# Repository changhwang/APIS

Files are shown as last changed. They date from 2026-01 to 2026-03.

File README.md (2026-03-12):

# APIS: Automated Polarization Imaging System

APIS (Latin for 'bee') is a control system for an automated 2-axis polarization imaging setup using Arduino, Python (PyQt6), and XIMEA cameras.

---

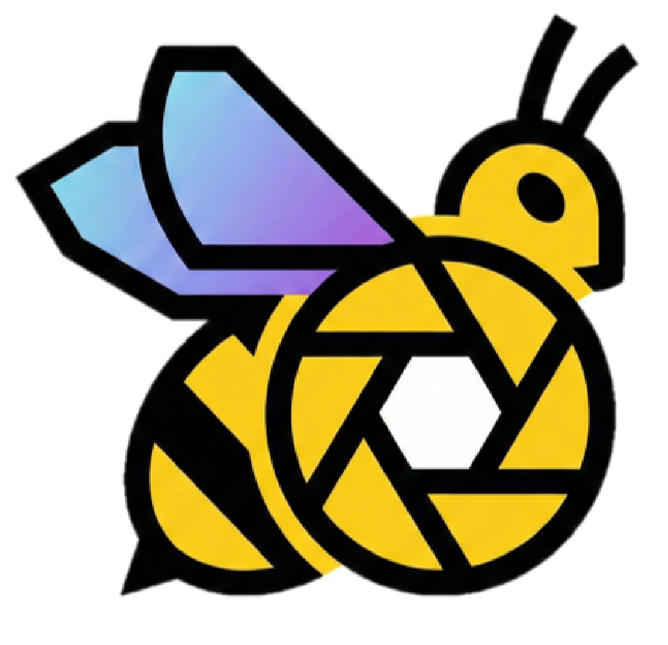
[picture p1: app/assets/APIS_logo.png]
APIS logo


---

## 0. Quick Start
1) Install XIMEA drivers + xiAPI, and flash Arduino firmware
2) Build the hardware by following `docs/hardware_assembly_guide.md` and `docs/implementation_guide.md`
3) Review the calibration notes in `docs/implementation_guide.md`
4) Run `python app/main.py`
5) Connect Camera, Connect Controller, press RESET/ARM, then START SEQUENCE

---

## 1. What You Get

- GUI application (live view, manual motor control, and sequence automation)
- Safety logic (LATCHED/ARMED, ESTOP, RESET)
- Live RGB preview + RGB snapshot capture
- RAW16 sequence capture + CSV/JSON metadata logging
- RAW16 to RGB8 preview conversion tool
- Hardware check tool for quick diagnostics

---

## 2. Requirements

### Hardware
- Hardware assembly guide: `docs/hardware_assembly_guide.md`
  - Follow this guide for the printed parts, stage stack-up, bearings, and gear assembly.
- Hardware implementation guide: `docs/implementation_guide.md`
  - Follow this guide for the physical build, wiring, calibration, and verification steps.
- Controller: Arduino Uno (used in our lab setup; other compatible Arduino boards may also work)
- Polarizer motor (Axis 1): SG90 servo @ Pin 10
- Sample motor (Axis 2): HS-318 servo @ Pin 11
- Camera: XIMEA USB 3.0/3.1 camera
- Polarizer film: Edmund Optics `50 mm Dia. Linear Polarizing Film (XP42-18)`, PN `29490`
- Analyzer polarizer: mount a second linear polarizer in front of the camera lens for cross-polarization imaging
- Backlight: MORITEX MEBL-CW7050 with MLEK-A080W2LR (used in our lab setup)
  - Other backlight models can be used.
  - Mechanical/optical design should be adapted to the selected backlight specifications.
- Bearing balls: McMaster-Carr `9292K74`, hard wear-resistant 52100 alloy steel balls, `5.5 mm` diameter
- Fasteners: M3 screws for printed-part assembly and support-layer fastening
- Threaded inserts: Female-thread brass knurled threaded insert embedment nuts (heat-set inserts)
  - Inserts are embedded into the printed parts with a soldering iron before final mechanical assembly.
- External power adapter: UNIFIVE UN318-1215, 12V 1.5A
- Servo power regulator: LM2596/LM2596S DC-DC buck converter module
  - Example: JTAREA LM2596 adjustable module (4.0-40V to 1.25-37V, 2A, LED voltmeter)
  - Role in this implementation: `VIN/GND` from Arduino feeds the regulator input, and the regulator output powers the HS-318 servo.
- Printed STL parts:
  - `parts/support_1stfloor.stl`
  - `parts/support_2ndfloor.stl`
  - `parts/support_3rdfloor.stl`
  - `parts/support_4thfloor.stl`
  - `parts/polarizer_stage_gear.stl`
  - `parts/film_stage_gear.stl`
  - `parts/servo_gear.stl`
- Power wiring used in this implementation
  - `UNIFIVE UN318-1215 12V 1.5A` powers the Arduino.
  - `Arduino VIN/GND` is connected to the regulator `VIN/GND`.
  - `Arduino 5V/GND` powers the SG90 servo.
  - `Regulator VOUT/GND` powers the HS-318 servo.
  - Arduino and both servos share ground.
- Calibration
  - Both polarizer and sample stages use an image-derived calibration ratio in Python.
  - Current stage calibration is based on `data/calibrationsample/normal`.
  - Current calibrated stage-to-servo ratio is `1.059` for both axes.
  - With the current `0-180` servo command range, the calibrated software max angle is `169 deg` per stage.
  - Re-run calibration after reprinting parts, changing gear fit, or remounting servos.
  - For the cross-polarized crystallinity imaging workflow targeted by this build, the required operating states fall within a limited angular working envelope, so a compact servo-driven transmission was appropriate for the current system.
  - If a future version needs reliable motion well beyond this working envelope, upgrade the mechanical drive by changing the transmission ratio or moving to a stepper-based axis.

### Software
- Python 3.9+
- Arduino IDE (for flashing firmware)
- XIMEA Windows Software Package (drivers + xiAPI)

---

## 3. Installation (Development)

### 3.1 Create venv and install deps
```bash
python -m venv venv
venv\Scripts\activate
pip install -r requirements.txt
```

### 3.2 XIMEA Python API (xiAPI)
The XIMEA Python API is not on PyPI. Install the XIMEA Software Package first, then link the API into your venv.

1. Install the XIMEA Software Package (drivers + API)
2. Locate the API folder (default):
   - `C:\XIMEA\API\Python\v3`
3. Copy the `ximea` folder into:
   - `APIS\venv\Lib\site-packages\`

Verification:
```bash
python -c "import ximea; print('Success')"
```

---

## 4. Quick Start

### 4.1 Flash Firmware
Open `firmware/APIS_Firmware/APIS_Firmware.ino` and upload to your Arduino.

### 4.2 Run GUI
```bash
python app/main.py
```

If you are assembling the hardware from scratch, complete the mechanical assembly in `docs/hardware_assembly_guide.md` and the wiring/verification steps in `docs/implementation_guide.md` before running the GUI.

---

## 5. App Usage Guide

### Safety Bar (Top)
- Shows controller/camera state and current angles/exposure/gain
- ESTOP: immediately cuts motor torque (LATCHED)
- RESET / ARM: re-engages motors (ARMED)
- HOME: moves both motors to 0 degrees

### Device Connections
- Select COM port -> Connect Controller
- Connect Camera
- If XIMEA is not available, the app falls back to DummyCamera

### Manual Motor Control (Absolute Movement)
- Set absolute stage angle within the calibrated software range and click Move
- +45 buttons increment by 45 degrees

### Camera Settings
- Set exposure (us) and gain (dB)
- Click Apply Settings
- The live-view exposure default is `18000 us`
- For the current XIMEA acquisition baseline, auto white balance is disabled during capture.
- Camera gamma is fixed to `1.0` for both live view and sequence capture.
- Fixed white balance is currently `R=1.40`, `G=1.00`, `B=1.20` for both Normal and Crosspol acquisition.
- Re-check the fixed WB values if illumination, analyzer/polarizer alignment, or optics are changed.

### Live View and Snapshot
- Live view uses `XI_RGB24`
- Snapshot saves preview RGB TIFF to the selected folder
- Snapshot metadata is logged to `snapshot_log.csv`

### Sequence Control
- Set Save Directory and Sample ID
- Choose modes: Crosspol / Normal
- Set exposures (defaults: Crosspol `50000 us`, Normal `18000 us`)
- Set angles (list or range, within the calibrated software range)
  - List: `90,60,45,30,0`
  - Range: `0:169:15`
- Settling Time: motor settle delay after each move
- Sequence capture uses `XI_RAW16` only
- During sequence capture, live view is paused and restored after completion
- Sequence images are saved as Bayer RAW `uint16 TIFF` without demosaicing or gamma

### Polarizer Angles (Sequence)
- Crosspol: polarizer moves to 90 degrees
- Normal: polarizer moves to 0 degrees

### Image Conversion
- Convert saved RAW16 TIFFs into confirmation-only `RGB8` previews
- Input scope: the selected folder and its immediate child folders
- Output folder: `<selected_folder>_rgb`
- Conversion pipeline: demosaic (`GBRG`) -> fixed white balance -> gamma `1/2.2`
- Original RAW16 files are preserved

---

## 6. Outputs

- Images:
  - `{SaveDir}/{SampleID}/crosspol`
  - `{SaveDir}/{SampleID}/normal`
- Log file:
  - `{SaveDir}/{SampleID}/{SampleID}_log.csv`
- Sequence metadata:
  - `{SaveDir}/{SampleID}/{SampleID}_metadata.json`
- Snapshot log:
  - `{SaveDir}/snapshot_log.csv`
- Optional RGB preview conversion:
  - `{SelectedFolder}_rgb/`
  - Example: `{SaveDir}/{SampleID}_rgb/crosspol/*_rgb.tif`

---

## 7. Safety Logic

- LATCHED: default on boot or ESTOP, motors detached
- ARMED: motors attached, motion enabled
- Commands are rejected in LATCHED state

---

## 8. Verification

- Automated tests: `tests/test_mock_serial.py`
- Manual hardware check: `scripts/check_hardware.py`
- Raw servo endpoint test (within firmware-supported `0-180` servo range): `scripts/test_servo_limits.py`
- Distribution includes `check_hardware` for quick COM port and ESTOP validation

---

## 9. Build and Distribution (Windows)

Recommended flow:
1) PyInstaller onedir build
2) Zip the dist folder for distribution
3) (Later) Inno Setup for installer packaging

### Build prerequisites
- Use a clean build venv with PyQt6 only (do not install PySide6/PyQt5)
- Icon file: `assets/icon.ico` (already provided)

### Build (spec-based)
- Spec files: `build/apis.spec`, `build/check_hardware.spec`
- Build script: `build/build.ps1`

Example:
```powershell
.\build\build.ps1 -Version 0.1.2
```

### Distribution package
The build script produces:
- `dist/APIS/` (GUI app)
- `dist/check_hardware/` (console tool)
- `release/APIS-win64-vX.Y.Z.zip` containing:
  - `APIS/`
  - `check_hardware/`
  - `README.txt`
  - `prereq_checklist.md`

### XIMEA prerequisite
XIMEA drivers/xiAPI must be installed first. The EXE does not bundle the SDK.

---

## 10. Repository Notes

- `data/`, `dist/`, and `release/*.zip` are ignored by git
- `.vscode/` and `build_venv/` are ignored by git

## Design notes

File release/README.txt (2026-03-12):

APIS (Automated Polarization Imaging System)

Package version: v0.1.2

Installation and Run (Windows)
1) Install prerequisites (see prereq_checklist.md)
2) Unzip the distribution package
3) Run APIS\APIS.exe

Recommended first-time checks
- Connect camera and confirm live view
- Connect Arduino, press RESET/ARM, and perform a manual move
- Use check_hardware.exe to validate COM port and ESTOP

Notes
- Do not move APIS.exe out of the APIS folder. Keep the whole folder.
- If the camera is not detected, verify XIMEA drivers are installed.
- Live view and Snapshot use RGB preview output.
- Sequence capture uses RAW16 TIFF output with per-sequence CSV and JSON metadata.
- Default acquisition baseline: Normal = polarizer 0 deg @ 18000 us, Crosspol = polarizer 90 deg @ 50000 us.
- Current XIMEA capture baseline uses fixed white balance: R=1.40, G=1.00, B=1.20.
- The app also includes a RAW16 to RGB preview conversion tool for saved datasets.

Hardware check
- Run check_hardware.exe to validate Arduino COM port and ESTOP without launching the GUI.

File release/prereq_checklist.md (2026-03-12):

# APIS Prerequisite Checklist (Windows)

## 1) XIMEA Software Package
- Install XIMEA Windows Software Package (drivers + xiAPI)
- Reboot after driver installation
- Confirm camera shows in Device Manager or XIMEA tools

## 2) Run APIS
- Launch APIS.exe
- Click Connect Camera and confirm live view
- Confirm the camera stream looks reasonable with the fixed white-balance baseline used by the app

## 3) Arduino / Motor Check
- Run `check_hardware.exe` to validate the Arduino COM port (motor controller)
- Press RESET / ARM
- Move Polarizer and Sample manually
- Press ESTOP and confirm torque release, then RESET

## 4) Sequence Smoke Test
- Set Sample ID and Save Directory
- Run a short sequence
- Default sequence baseline: Normal `18000 us`, Crosspol `50000 us`
- Verify RAW16 TIFF images, `{SampleID}/{SampleID}_log.csv`, and `{SampleID}/{SampleID}_metadata.json` are created
- Verify live view returns after the sequence finishes

Troubleshooting order
1) XIMEA drivers
2) Camera connection
3) Arduino COM/serial
4) APIS app

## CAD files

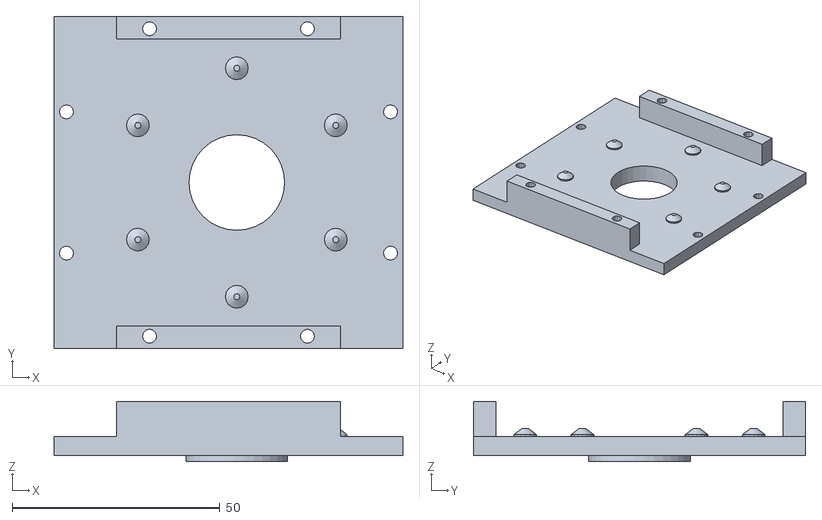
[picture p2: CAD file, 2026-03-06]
parts/support_3rdfloor.stl
84.0 x 80.0 x 14.5

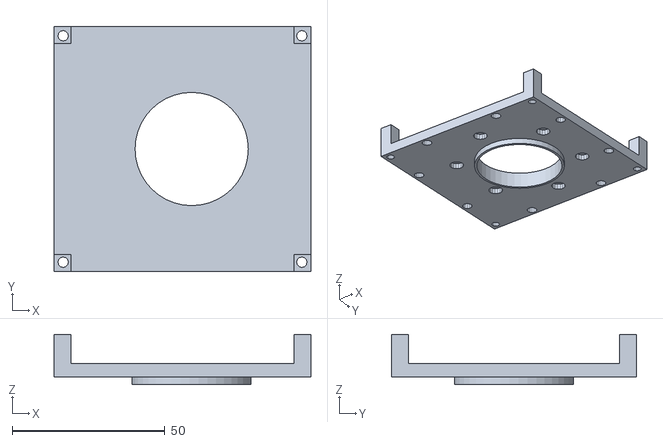
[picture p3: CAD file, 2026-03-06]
parts/support_2ndfloor.stl
84.0 x 80.0 x 16.5

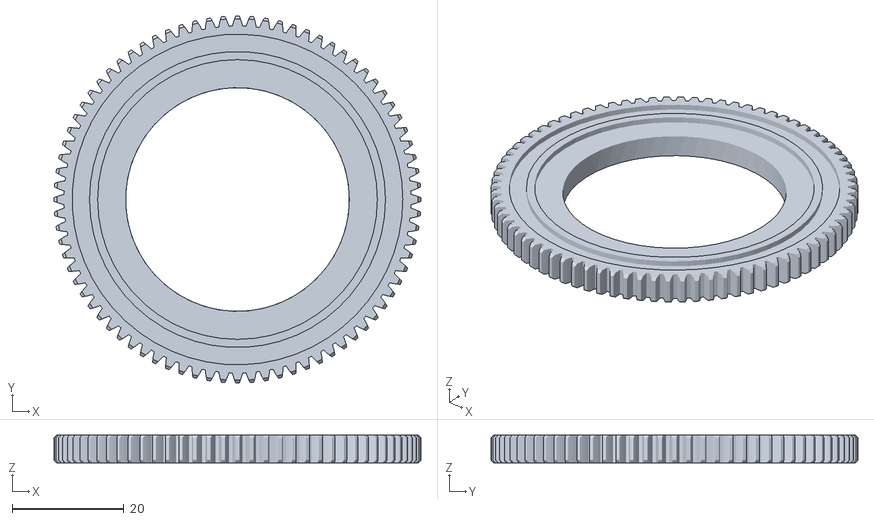
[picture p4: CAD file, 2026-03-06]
parts/polarizer_stage_gear.stl
65.6 x 65.6 x 5.00

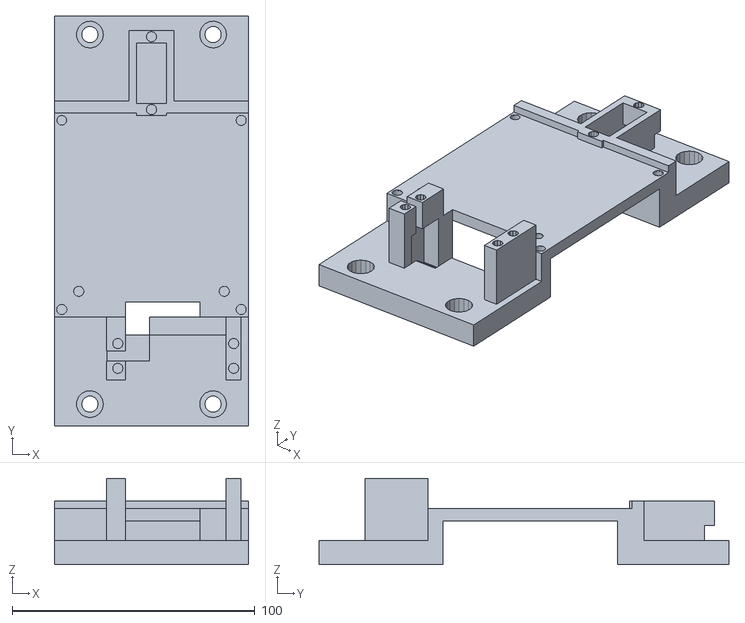
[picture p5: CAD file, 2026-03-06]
parts/support_1stfloor.stl
80.0 x 169.0 x 35.5

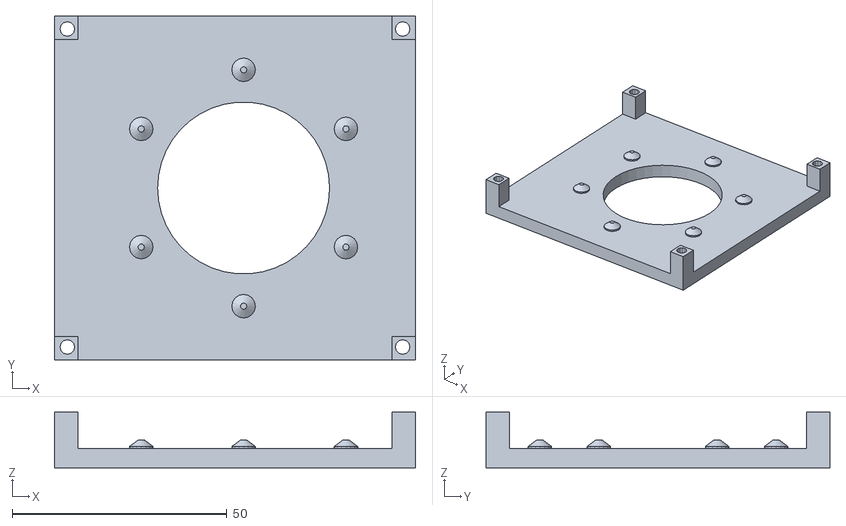
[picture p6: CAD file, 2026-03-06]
parts/support_4thfloor.stl
84.0 x 80.0 x 13.0

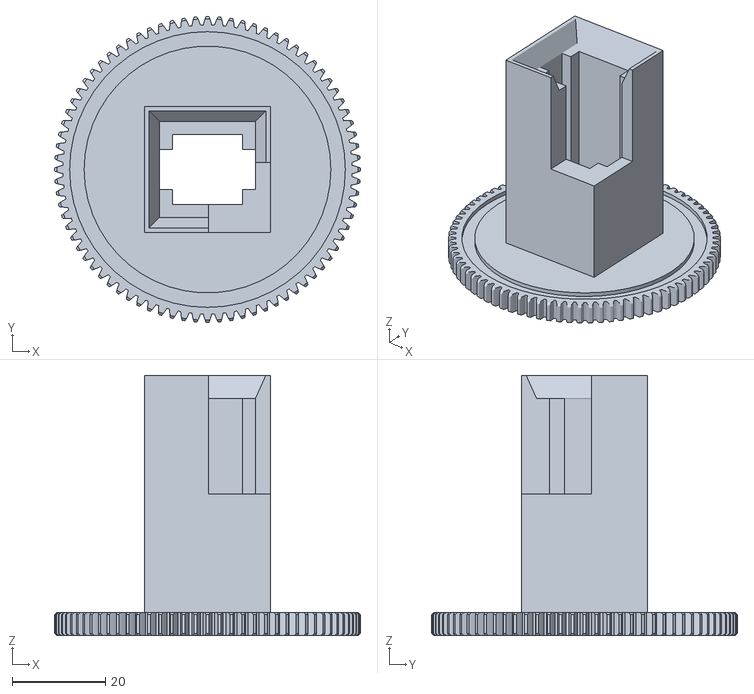
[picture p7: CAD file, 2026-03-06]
parts/film_stage_gear.stl
65.6 x 65.6 x 55.8

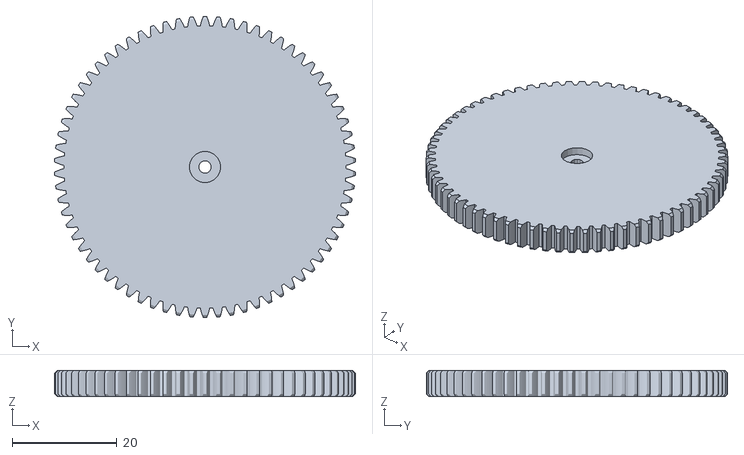
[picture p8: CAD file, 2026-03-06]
parts/servo_gear.stl
57.6 x 57.6 x 5.00

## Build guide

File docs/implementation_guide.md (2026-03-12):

# APIS Hardware Implementation Guide

## 1. Purpose

This document explains how to assemble and reproduce the APIS (Automated Polarization Imaging System) hardware. It covers the BOM, wiring architecture, Arduino pin mapping, implementation steps, calibration, and the verification checklist. The guide is based on the current firmware in `firmware/APIS_Firmware/APIS_Firmware.ino` and the controller-side protocol in `apis/config.py` and `apis/controller.py`.

For the mechanical stack-up, printed parts, bearings, and stage assembly order, see `docs/hardware_assembly_guide.md`.

## 2. System Overview

APIS is a 2-axis polarization imaging platform built around two servos, an Arduino controller, a host PC, and a XIMEA camera.

- Axis 1: SG90 servo for polarizer rotation
- Axis 2: HS-318 servo for sample rotation
- Controller: Arduino Uno
- Host PC: Python GUI communicating over USB serial
- Camera: XIMEA USB camera
- Light source: MORITEX backlight or equivalent

The control flow is:

1. The PC sends `PPAAA` commands over USB serial at `9600` baud.
2. The Arduino drives the two servo axes.
3. The camera is connected directly to the PC.
4. The SG90 is powered from Arduino `5V/GND`, while the HS-318 is powered from the regulator output. Grounds are shared.

## 3. BOM

### 3.1 Required Parts

| Category | Item | Recommended / Used | Qty | Notes |
| --- | --- | --- | --- | --- |
| Controller | Arduino board | Arduino Uno | 1 | Matches current firmware |
| Servo motor | Polarizer axis servo | SG90 | 1 | Signal on pin 10 |
| Servo motor | Sample axis servo | HS-318 | 1 | Signal on pin 11 |
| Camera | Industrial camera | XIMEA USB 3.0/3.1 camera | 1 | Connected directly to PC |
| Illumination | Backlight | MORITEX MEBL-CW7050 + MLEK-A080W2LR | 1 | Lab-used combination |
| Power | External power adapter | UNIFIVE UN318-1215, 12V 1.5A | 1 | Main power input |
| Power regulation | DC-DC buck converter | LM2596 / LM2596S module | 1 | Powers HS-318 |
| Wiring | Jumper wires / hookup wires | Mixed male-female and male-male | 1 set | For signal and power |
| Mechanical | Fasteners | M3 screws | 1 set | Printed-part stack and support-layer fastening |
| Mechanical | Threaded inserts | Female-thread brass knurled threaded insert embedment nuts | 1 set | Heat-set into printed parts with a soldering iron |
| Mechanical | Polarizer holder / sample stage | Custom jig | 1 set | Depends on fixture design |

### 3.2 Recommended Accessories

| Item | Qty | Purpose |
| --- | --- | --- |
| Solderless breadboard or terminal block | 1 | Power distribution |
| Multimeter | 1 | Voltage setup and wiring validation |
| USB cable for Arduino | 1 | Firmware upload and serial connection |

## 4. Firmware Pin Map

The current firmware uses the following fixed pin map:

| Function | Arduino Pin | Device |
| --- | --- | --- |
| Polarizer servo signal | D10 | SG90 |
| Sample servo signal | D11 | HS-318 |
| Serial communication | USB Serial | PC GUI / scripts |

Serial protocol:

- Baudrate: `9600`
- Command format: `PPAAA\n`
- Examples:
  - `98000`: RESET / ARM
  - `99000`: ESTOP
  - `96000`: HOME
  - `10090`: Polarizer to 90 degrees
  - `11045`: Sample to 45 degrees

## 5. Power and Wiring Architecture

### 5.1 Power Distribution

Build the power path as follows:

1. Connect the `UNIFIVE UN318-1215 (12V 1.5A)` adapter to the Arduino power input.
2. Connect Arduino `VIN/GND` to the regulator `VIN/GND`.
3. Connect Arduino `5V/GND` to the SG90 power pins.
4. Connect regulator `VOUT/GND` to the HS-318 power pins.
5. Keep Arduino, SG90, and HS-318 on a common ground.

Reference wiring:

```text
UNIFIVE UN318-1215 12V/1.5A
  -> Arduino power input

Arduino VIN/GND
  -> regulator VIN/GND

Arduino 5V/GND
  -> SG90 V+/GND

Regulator VOUT/GND
  -> HS-318 V+/GND
```

### 5.2 Core Rules

- Power the SG90 from Arduino `5V/GND`.
- Power the HS-318 from the regulator `VOUT/GND`.
- Share ground between Arduino and both servos.
- Route only servo signal lines to the Arduino digital pins.

### 5.3 System Power Layout

```text
UNIFIVE UN318-1215 12V/1.5A
   -> Arduino power input

Arduino VIN/GND
   -> regulator input VIN/GND

Arduino 5V/GND
   -> SG90 V+/GND

Regulator output VOUT/GND
   -> HS-318 V+/GND
```

This wiring matches the current firmware and control application.

## 6. Why Calibration Is Required

This system should be calibrated after assembly.

Calibration is necessary because:

- The gears are 3D printed rather than machined
- Servo gears are mounted directly onto the servo shafts with screws
- Female-thread brass heat-set inserts are embedded into printed parts during assembly
- Printed fit, backlash, concentricity, and servo mounting can vary from build to build
- The effective stage rotation can differ from the nominal design ratio

In practice, this means the commanded angle sent by software may not match the true stage angle unless the system is calibrated.

Current implementation status:

- Both axes use an image-derived calibration ratio in Python
- The current calibration dataset is `data/calibrationsample/normal`
- The current polarizer-stage and sample-stage stage-to-servo ratio is `1.059`
- This corresponds to an effective measured stage response of about `0.944 x commanded_angle`
- With the current `0-180` servo command range, the current software limit is `169 deg` per stage

Because the calibrated ratio is greater than `1.0`, the maximum stage angle is still lower than the maximum raw servo command. With the current settings, `169 deg` is the largest stage angle that still maps inside the `0-180` servo command range.

For the cross-polarized crystallinity imaging workflow targeted by this build, the required operating states fall within a limited angular working envelope. For that reason, a compact servo-driven transmission was appropriate for the current system architecture.

If a future version needs reliable travel well beyond this range, the preferred upgrade paths are:

- Change the transmission ratio so the required stage range fits inside the servo's usable motion
- Replace the current servo-driven axes with a stepper-motor-based drive for a wider and more repeatable rotation range

## 7. Wiring Guide

### 6.1 Polarizer Axis (SG90)

Typical SG90 wire colors are:

- Brown or black: GND
- Red: +5V
- Orange or yellow: Signal

Connect:

- SG90 Signal -> Arduino `D10`
- SG90 V+ -> Arduino `5V`
- SG90 GND -> Arduino `GND`

### 6.2 Sample Axis (HS-318)

Wire colors may vary by vendor, so confirm against the actual servo before powering it.

Connect:

- HS-318 Signal -> Arduino `D11`
- HS-318 V+ -> Regulator `VOUT`
- HS-318 GND -> Regulator `GND`

### 6.3 Arduino

Connect:

- Arduino USB -> Host PC
- UNIFIVE UN318-1215 12V 1.5A -> Arduino power input
- Arduino `VIN/GND` -> Regulator `VIN/GND`
- Arduino `5V/GND` -> SG90 `V+/GND`
- Arduino `D10` -> SG90 Signal
- Arduino `D11` -> HS-318 Signal

Notes:

- Confirm regulator input and output labels on the actual module before powering the system.
- Keep all grounds tied together.

### 6.4 Text Wiring Diagram

```text
PC USB
  -> Arduino Uno USB

UNIFIVE UN318-1215 12V/1.5A
  -> Arduino power input

Arduino VIN/GND
  -> regulator VIN/GND

Arduino 5V/GND
  -> SG90 V+/GND

Arduino D10
  -> SG90 signal

Arduino D11
  -> HS-318 signal

Regulator VOUT/GND
  -> HS-318 V+/GND
```

## 8. Implementation Procedure

### Step 1. Prepare the Power Path

1. Connect the `UNIFIVE UN318-1215 12V 1.5A` adapter to the Arduino power input.
2. Connect Arduino `VIN/GND` to regulator `VIN/GND`.
3. Use a multimeter to set the regulator output voltage for the HS-318.
4. Connect Arduino `5V/GND` to SG90 `V+/GND`.

### Step 2. Connect the Signal Lines

1. Connect the SG90 signal line to Arduino `D10`.
2. Connect the HS-318 signal line to Arduino `D11`.
3. Verify that Arduino `GND`, SG90 `GND`, and regulator `GND` are common.

### Step 3. Connect Servo Power

1. Connect SG90 `V+/GND` to Arduino `5V/GND`.
2. Connect HS-318 `V+/GND` to regulator `VOUT/GND`.
3. Recheck polarity before applying power.

### Step 4. Upload Firmware

1. Open `firmware/APIS_Firmware/APIS_Firmware.ino` in the Arduino IDE.
2. Select the Arduino Uno board profile.
3. Select the correct COM port and upload the firmware.

### Step 5. Initial Verification

1. Confirm the serial connection shows `READY`.
2. Use the APIS app or `scripts/check_hardware.py` to verify controller connection.
3. Send `RESET` and verify both axes move correctly.
4. Trigger `ESTOP` and verify torque is released immediately.
5. If needed, run `scripts/test_servo_limits.py` to probe raw servo endpoint behavior inside the firmware-supported `0-180` range.

### Step 6. Run Stage Calibration

1. Place a calibration target or asymmetric sample on the stage being calibrated.
2. Capture a `normal` sequence across known commanded angles such as `0, 15, 30, ...`.
3. Run:

```bash
python scripts/analyze_stage_calibration.py data/calibrationsample/normal
```

4. Review the reported `Recommended stage_to_servo_ratio`.
5. Update `POLARIZER_STAGE_TO_SERVO_RATIO` and/or `SAMPLE_STAGE_TO_SERVO_RATIO` in `apis/config.py` if new calibrated values are required.
6. Re-test manual motion and sequence acquisition after changing the ratio.

## 9. Operational Behavior

The firmware state machine directly affects the hardware behavior:

- Boot state: `LATCHED`
- `LATCHED`: servos detached, motion commands blocked
- `RESET (98)`: servos attached, system enters `ARMED`
- `ESTOP (99)`: servos detached, system returns to `LATCHED`
- `HOME (96)`: both axes move to 0 degrees
- `10AAA`: polarizer angle command
- `11AAA`: sample angle command

Practical implications:

- The servos do not move automatically at power-on.
- Motion is enabled only after `RESET`.
- During `ESTOP`, torque is released, so the mechanical structure must tolerate free movement.

## 10. Sequence Behavior

The Python sequence controller uses the hardware as follows:

- Crosspol mode:
  - Polarizer = 90 degrees
  - Sample = stepped through multiple angles
- Normal mode:
  - Polarizer = 0 degrees
  - Sample = stepped through multiple angles

Default sample angle example:

- `90, 60, 45, 30, 0`

Mechanical design should therefore support:

- Stable polarizer movement across at least `0-90` degrees
- Stable sample movement across the full calibrated range
- A clearly defined physical zero position for each axis

### 10.1 Camera Acquisition Baseline

For the current XIMEA-based acquisition setup:

- Auto exposure / auto gain should remain disabled during capture
- Camera gamma should remain fixed at `1.0`
- Auto white balance should remain disabled during capture
- The current fixed white-balance baseline is `R=1.40`, `G=1.00`, `B=1.20`
- The same fixed white-balance values should be used for both Normal and Crosspol images so color differences remain comparable across modes
- Re-evaluate the fixed white-balance values if the illumination path, optics, or analyzer/polarizer alignment changes
- Live preview should use `XI_RGB24`
- Sequence capture should use `XI_RAW16`
- The current validated sequence exposure baseline is:
  - Normal / PPL: `18000 us`
  - Crosspol / XPL: `50000 us`
- Sequence outputs should be saved as Bayer RAW `uint16 TIFF` plus per-sequence CSV and JSON metadata

## 11. Verification Checklist

- The UNIFIVE UN318-1215 12V 1.5A adapter is connected correctly to the Arduino power input
- Arduino `VIN/GND` is connected correctly to regulator `VIN/GND`
- Arduino `5V/GND` is connected correctly to the SG90
- Regulator `VOUT/GND` is connected correctly to the HS-318
- Regulator `GND` and Arduino `GND` are common
- SG90 is on `D10` and HS-318 is on `D11`
- `READY -> RESET -> move -> ESTOP` works as expected
- Motion commands are rejected after `ESTOP`
- No mechanical interference occurs across the full calibrated motion range
- Sample-stage calibration has been run after assembly or rebuild
- Polarizer-stage calibration has been run after assembly or rebuild
- The configured stage max angle matches the current calibration result
- XIMEA acquisition uses fixed white balance rather than auto white balance

## 12. Notes

- Effective range, torque, and deadband vary by servo model and clone quality.
- Servo wire colors may differ by vendor.
- This document focuses on the servo control and system integration path rather than full camera or lighting electrical detail.
- `ESTOP` detaches the servos, so the axes may move freely afterward.

## 13. Improvement Opportunities

The current implementation is suitable for operation, but the following upgrades would improve maintainability and repeatability:

- Replace loose power branching with a perma-proto board or small distribution board
- Use connectorized wiring between servos, regulator, and Arduino
- Add labels for power input, servo power output, and signal lines
- Add a simple wiring schematic image for faster assembly by new users
- Add fixture photos, mechanical sketches, and an initial calibration document

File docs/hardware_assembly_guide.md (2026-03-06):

# APIS Hardware Assembly Guide

## 1. Purpose

This document explains the mechanical assembly of the APIS platform using the STL files in `parts/`. It covers the printed parts, stage stack-up, bearing layout, gear pairing, and the order of assembly for the polarizer and sample rotation system.

## 2. Printed Parts

The current mechanical design uses the following STL files:

- `parts/support_1stfloor.stl`
- `parts/support_2ndfloor.stl`
- `parts/support_3rdfloor.stl`
- `parts/support_4thfloor.stl`
- `parts/polarizer_stage_gear.stl`
- `parts/film_stage_gear.stl`
- `parts/servo_gear.stl`

## 3. Purchased Mechanical and Optical Parts

- Servo for polarizer axis: SG90
- Servo for sample axis: HS-318
- Bearing balls: McMaster-Carr `9292K74`, hard wear-resistant 52100 alloy steel balls, `5.5 mm` diameter
- Polarizer film: Edmund Optics `50 mm Dia. Linear Polarizing Film (XP42-18)`, PN `29490`
- Analyzer polarizer for camera: mount a second linear polarizer in front of the camera lens
- Fasteners: M3 screws
- Threaded inserts: female-thread brass knurled threaded insert embedment nuts

The current build uses heat-set brass inserts in the printed parts. The female-thread inserts are embedded into the printed plastic with a soldering iron before the M3 screws are installed.

## 4. Gear Set Definition

The motion system is based on two gear sizes.

### Large Gear

- Teeth: `80T`
- Module: `0.8`
- Pitch diameter: `64 mm`
- Outside diameter: `65.6 mm`

Used for:

- `polarizer_stage_gear`
- `film_stage_gear`

### Small Gear

- Teeth: `70T`
- Module: `0.8`
- Pitch diameter: `56 mm`
- Outside diameter: `57.6 mm`

Used for:

- `servo_gear`

Each servo receives one `servo_gear`, and each `servo_gear` meshes horizontally with one large stage gear.

## 5. Stage Architecture

The system is assembled as a vertical stack of floors.

### First Floor

- Base support structure
- SG90 mounted for the polarizer axis
- HS-318 mounted for the sample axis
- Backlight mounted into the first-floor support

### Second Floor

- Supports and fixes the backlight position
- Provides the bearing race for the polarizer stage
- Works with the underside of the polarizer gear to create a ball-bearing rotation interface

### Polarizer Stage

- `polarizer_stage_gear` sits above the second-floor support
- The stage holds the circular polarizer film
- A SG90-mounted `servo_gear` meshes with the `polarizer_stage_gear`
- A second polarizer is mounted in front of the camera lens so the system can operate in cross-polarization mode

### Third Floor

- Supports the upper sample stage assembly
- Provides another circular bearing race for the sample stage
- Works with the underside of the sample gear/stage assembly to create a second ball-bearing rotation interface

### Sample Stage

- `film_stage_gear` sits above the third-floor support
- The printed part combines the large gear and the sample stage
- An HS-318-mounted `servo_gear` meshes with the `film_stage_gear`

### Fourth Floor

- Top support / retention structure
- Final mechanical stabilization for the upper assembly

## 6. Bearing Interface Design

Both rotating stages use the same bearing concept.

1. The underside of the rotating gear includes five cylindrical bearing pockets.
2. The supporting floor below includes a donut-shaped circular race.
3. Five `5.5 mm` steel balls are placed into the race/pocket interface.
4. The rotating gear rests on the five balls and can rotate smoothly.

This structure is used twice:

- Between `support_2ndfloor` and `polarizer_stage_gear`
- Between `support_3rdfloor` and `film_stage_gear`

## 7. Polarizer Stage Assembly

Build the polarizer stage as follows:

1. Heat-set the brass threaded inserts into the printed parts that receive M3 fasteners.
2. Install the SG90 into `support_1stfloor`.
3. Mount the backlight into `support_1stfloor`.
4. Install `support_2ndfloor` so the backlight position is fixed.
5. Place five McMaster-Carr `9292K74` balls into the donut-shaped bearing path in the second-floor support.
6. Insert the polarizer film into `polarizer_stage_gear`.
7. Position the `polarizer_stage_gear` so its lower bearing pockets sit on the five balls.
8. Mount a `servo_gear` onto the SG90 shaft.
9. Mesh the SG90 `servo_gear` horizontally with the `polarizer_stage_gear`.

## 8. Sample Stage Assembly

Build the sample stage as follows:

1. Confirm that all required brass inserts are embedded in the upper printed supports before stack-up continues.
2. Install `support_3rdfloor` above the polarizer stage assembly.
3. Place five McMaster-Carr `9292K74` balls into the donut-shaped bearing path in the third-floor support.
4. Position `film_stage_gear` above the balls so the lower bearing pockets sit correctly on the ball set.
5. Mount a second `servo_gear` onto the HS-318 shaft.
6. Mesh the HS-318 `servo_gear` horizontally with `film_stage_gear`.
7. Install `support_4thfloor` as the upper retaining/support layer.

## 9. Full Assembly Order

Assemble the full system in this order:

1. Print all STL parts in `parts/`.
2. Heat-set the female-thread brass threaded inserts into the printed parts using a soldering iron.
3. Mount SG90 and HS-318 to `support_1stfloor`.
4. Mount the backlight to `support_1stfloor`.
5. Install `support_2ndfloor`.
6. Add five bearing balls to the second-floor bearing race.
7. Install the `polarizer_stage_gear` with polarizer film inserted.
8. Mount the SG90 `servo_gear` and mesh it with the polarizer stage gear.
9. Install `support_3rdfloor`.
10. Add five bearing balls to the third-floor bearing race.
11. Install the `film_stage_gear`.
12. Mount the HS-318 `servo_gear` and mesh it with the sample stage gear.
13. Install `support_4thfloor`.
14. Secure printed parts and retained components with M3 screws into the heat-set inserts.
15. Complete electrical wiring using `docs/implementation_guide.md`.
16. Upload firmware and verify stage movement.
17. Run stage calibration as described in `docs/implementation_guide.md`.

## 10. Motion Summary

The motion path is:

- SG90 -> `servo_gear` -> `polarizer_stage_gear` -> polarizer rotation
- HS-318 -> `servo_gear` -> `film_stage_gear` -> sample rotation

The large gears carry the functional stage bodies, while the small gears are mounted directly to the servo shafts.

For cross-polarization imaging:

- One polarizer is mounted in `polarizer_stage_gear`
- A second polarizer is mounted in front of the camera lens and acts as the analyzer
- Cross-polarization is produced by the relative orientation between the stage polarizer and the lens-side analyzer

For the cross-polarized crystallinity imaging workflow targeted by this build, the required operating states fit within a limited angular working envelope, so the present servo-driven gear train is appropriate for the current assembly.

## 11. Assembly Checks

- Both servos are firmly fixed to `support_1stfloor`
- Backlight is centered and secured before upper floors are installed
- Each bearing interface contains exactly five `5.5 mm` steel balls
- The stage gears sit evenly on the ball sets without binding
- Each `servo_gear` meshes cleanly with its matching large gear
- All required heat-set brass inserts are seated flush and retain M3 screws securely
- The polarizer film is seated securely in `polarizer_stage_gear`
- The sample holder area on `film_stage_gear` is level and centered
- Upper support layers do not rub against the rotating gears
- A fresh calibration is performed after final assembly

## 12. Improvement Opportunities

- Add an exploded assembly diagram showing the full floor-by-floor stack
- Add dimensions or tolerances for servo mounting holes and bearing pockets
- Add a fixture drawing for polarizer film insertion and sample mounting
- Use a perma-proto board or fixed wiring bracket to clean up cable routing around the moving stages
- If future versions require reliable rotation well beyond the current working envelope, update the gear ratio or upgrade the axes to a stepper-motor-based drive

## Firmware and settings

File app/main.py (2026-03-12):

import sys
import os
import time
import logging
import ctypes
import cv2
import re
import numpy as np
from PyQt6.QtWidgets import (
    QApplication, QMainWindow, QWidget, QVBoxLayout, QHBoxLayout, 
    QLabel, QPushButton, QComboBox, QGroupBox, QSpinBox, QCheckBox,
    QDoubleSpinBox, QSlider, QLineEdit, QProgressBar, QTextEdit, 
    QFileDialog, QMessageBox, QFrame, QGridLayout
)
from PyQt6.QtCore import Qt, pyqtSlot, QTimer
from PyQt6.QtGui import QImage, QPixmap, QColor, QPalette, QIcon

# Add project root to path
sys.path.append(".") 

from apis.controller import PicsController
from apis.sequence import PicsSequence
from apis import config, utils, io
from app.workers import CameraThread, SequenceThread, DummyCamera, XimeaCamera

# --- UI STATES ---
STATE_DISCONNECTED = "DISCONNECTED"
STATE_LATCHED = config.STATE_LATCHED # "LATCHED"
STATE_ARMED = config.STATE_ARMED     # "ARMED"
STATE_RUNNING = "RUNNING"
STATE_ERROR = "ERROR"

class MainWindow(QMainWindow):
    def __init__(self):
        super().__init__()
        self.setWindowTitle("APIS (Automated Polarization Imaging System)")
        icon_candidates = [
            os.path.join(os.path.dirname(__file__), "assets", "apis_logo.png"),
            os.path.join(os.path.dirname(__file__), "..", "assets", "icon.ico"),
            os.path.join(os.path.dirname(__file__), "assets", "icon.ico"),
        ]
        for icon_path in icon_candidates:
            if os.path.isfile(icon_path):
                self.setWindowIcon(QIcon(icon_path))
                break
        self.resize(1400, 850)
        
        # 1. Init Base State & UI (Required for Logging)
        self.current_state = STATE_DISCONNECTED
        self.init_ui()
        
        # --- Logic Objects ---
        self.ctrl = PicsController()
        
        # Camera Initialization strategy
        # 1. Try XimeaCamera
        # 2. Fallback to DummyCamera if SDK missing
        self.cam = XimeaCamera()
        if not self.cam.check_available():
            logging.warning("Ximea SDK missing. Using Dummy Camera.")
            self.cam = DummyCamera()
            self.log("Initialized: DummyCamera (Simulation)", "WARN")
        else:
            self.log("Initialized: XimeaCamera (Hardware)")
            
        self.sequence_logic = PicsSequence(self.ctrl, self.cam)
        
        self.cam_thread = None
        self.seq_thread = None
        self._logged_frame_info = False
        self._logged_channel_stats = False
        self._force_bgr_swap = False
        self._last_frame_rgb = None
        self._exp_cross_last = config.XIMEA_DEFAULT_CROSSPOL_EXPOSURE_US
        self._exp_normal_last = config.XIMEA_DEFAULT_NORMAL_EXPOSURE_US
        
        # Initial UI Update
        self.update_state_ui(STATE_DISCONNECTED)

    def init_ui(self):
        central_widget = QWidget()
        self.setCentralWidget(central_widget)
        main_layout = QVBoxLayout(central_widget)
        main_layout.setContentsMargins(5, 5, 5, 5)
        main_layout.setSpacing(5)

        # 0. LOGGING (Must be first)
        self.log_text = QTextEdit()
        self.log_text.setReadOnly(True)
        self.log_text.setMaximumHeight(150)
        
        # Redirect Logger to UI
        logging.getLogger().setLevel(logging.INFO)

        # 1. TOP: SAFETY BAR
        self.safety_bar = self.create_safety_bar()
        main_layout.addWidget(self.safety_bar)

        # 2. MIDDLE: Split 3 Columns (Left: Devices, Center: Live, Right: Sequence)
        content_layout = QHBoxLayout()
        
        # Left Panel (Devices & Manual)
        left_panel = QVBoxLayout()
        left_panel.addWidget(self.create_connection_group())
        left_panel.addWidget(self.create_camera_settings_group())
        left_panel.addWidget(self.create_manual_control_group())
        left_panel.addStretch()
        content_layout.addLayout(left_panel, 1)

        # Center Panel (Live View)
        center_panel = QVBoxLayout()
        center_panel.addWidget(self.create_live_view_group())
        content_layout.addLayout(center_panel, 2)

        # Right Panel (Sequence)
        right_panel = QVBoxLayout()
        right_panel.addWidget(self.create_sequence_group())
        right_panel.addWidget(self.create_image_conversion_group())
        right_panel.addStretch()
        content_layout.addLayout(right_panel, 1)

        main_layout.addLayout(content_layout)

        # 3. BOTTOM: LOG
        log_layout = QHBoxLayout()
        self.btn_log_copy = QPushButton("Copy Log")
        self.btn_log_copy.clicked.connect(self.on_log_copy)
        self.btn_log_save = QPushButton("Save Log")
        self.btn_log_save.clicked.connect(self.on_log_save)
        log_layout.addStretch()
        log_layout.addWidget(self.btn_log_copy)
        log_layout.addWidget(self.btn_log_save)

        main_layout.addWidget(self.log_text)
        main_layout.addLayout(log_layout)
        
        # Redirect Logger to UI
        logging.getLogger().setLevel(logging.INFO)
        # (A fuller impl would attach a custom Handler, 
        #  here we just wrap log calls or rely on console for now + my log helper)
        
    def log(self, msg, level="INFO"):
        """Append log message to text area"""
        ts = time.strftime("%H:%M:%S")
        state = self.current_state
        formatted = f"[{ts}][{state}][{level}] {msg}"
        self.log_text.append(formatted)
        # Auto scroll
        sb = self.log_text.verticalScrollBar()
        sb.setValue(sb.maximum())
        print(formatted) # console backup

    # --- UI CREATION HELPERS ---
    
    def create_safety_bar(self):
        frame = QFrame()
        frame.setFrameShape(QFrame.Shape.StyledPanel)
        frame.setStyleSheet("background-color: #eee; border: 1px solid #ccc;")
        layout = QHBoxLayout(frame)
        
        self.lbl_status = QLabel("Controller: DISCONNECTED")
        self.lbl_status.setStyleSheet("font-size: 16px; font-weight: bold; color: gray;")
        
        self.lbl_cam_status = QLabel(" | Camera: DISCONNECTED")
        self.lbl_cam_status.setStyleSheet("font-size: 16px; font-weight: bold; color: gray;")

        self.lbl_info = QLabel(" | Pol: -- | Samp: -- | Exp: -- us | Gain: -- dB")
        self.lbl_info.setStyleSheet("font-size: 14px; color: #333;")
        
        self.btn_estop = QPushButton("E-STOP")
        self.btn_estop.setStyleSheet("background-color: red; color: white; font-weight: bold; font-size: 16px; padding: 10px;")
        self.btn_estop.clicked.connect(self.on_estop)
        
        self.btn_reset = QPushButton("RESET / ARM")
        self.btn_reset.setStyleSheet("background-color: #4CAF50; color: white; font-weight: bold; font-size: 16px; padding: 10px;")
        self.btn_reset.clicked.connect(self.on_reset)
        
        self.btn_home = QPushButton("HOME")
        self.btn_home.setStyleSheet("background-color: #e0e0e0; color: black; font-weight: bold; font-size: 16px; padding: 10px;")
        self.btn_home.clicked.connect(self.on_home)
        
        layout.addWidget(self.lbl_status)
        layout.addWidget(self.lbl_cam_status)
        layout.addWidget(self.lbl_info)
        layout.addStretch()
        layout.addWidget(self.btn_home)
        layout.addWidget(self.btn_reset)
        layout.addWidget(self.btn_estop)
        return frame

    def create_connection_group(self):
        grp = QGroupBox("Device Connections")
        layout = QGridLayout()
        
        # --- Arduino Section ---
        layout.addWidget(QLabel("<b>Arduino Controller</b>"), 0, 0, 1, 3)
        
        layout.addWidget(QLabel("Port:"), 1, 0)
        self.cmb_port = QComboBox()
        self.on_refresh_ports() # Populate initially
        layout.addWidget(self.cmb_port, 1, 1)
        
        self.btn_refresh = QPushButton("↻")
        self.btn_refresh.setFixedWidth(30)
        self.btn_refresh.setToolTip("Refresh COM Ports")
        self.btn_refresh.clicked.connect(self.on_refresh_ports)
        layout.addWidget(self.btn_refresh, 1, 2)
        
        self.btn_connect = QPushButton("Connect Controller")
        self.btn_connect.clicked.connect(self.on_toggle_connect)
        layout.addWidget(self.btn_connect, 2, 0, 1, 3)
        
        # --- Camera Section ---
        layout.addWidget(QLabel("<b>Camera</b>"), 3, 0, 1, 3)
        
        self.btn_cam_connect = QPushButton("Connect Camera")
        self.btn_cam_connect.clicked.connect(self.on_toggle_camera)
        layout.addWidget(self.btn_cam_connect, 4, 0, 1, 3)
        
        grp.setLayout(layout)
        return grp

    def create_camera_settings_group(self):
        grp = QGroupBox("Camera Settings")
        layout = QGridLayout()
        
        layout.addWidget(QLabel("Exposure (us):"), 0, 0)
        self.spin_exp = QSpinBox()
        self.spin_exp.setRange(100, 1000000)
        self.spin_exp.setValue(config.XIMEA_DEFAULT_NORMAL_EXPOSURE_US)
        self.spin_exp.setSingleStep(1000)
        layout.addWidget(self.spin_exp, 0, 1)
        
        layout.addWidget(QLabel("Gain (dB):"), 1, 0)
        self.spin_gain = QDoubleSpinBox()
        self.spin_gain.setRange(0.0, 24.0)
        self.spin_gain.setValue(0.0)
        layout.addWidget(self.spin_gain, 1, 1)
        
        self.btn_cam_apply = QPushButton("Apply Settings")
        self.btn_cam_apply.clicked.connect(self.on_cam_apply)
        layout.addWidget(self.btn_cam_apply, 2, 0, 1, 2)

        self.spin_exp.valueChanged.connect(self.update_status_info)
        self.spin_gain.valueChanged.connect(self.update_status_info)
        
        lbl_rec = QLabel("Rec: Crosspol=50,000us (50ms), Normal=18,000us (18ms)")
        lbl_rec.setStyleSheet("color: gray; font-size: 10px;")
        layout.addWidget(lbl_rec, 3, 0, 1, 2)
        
        grp.setLayout(layout)
        self.grp_camera = grp
        return grp

    def create_manual_control_group(self):
        grp = QGroupBox("Manual Motor Control (Absolute Movement)")
        layout = QGridLayout()
        
        # Polarizer
        layout.addWidget(QLabel("Polarizer (Pin 10):"), 0, 0, 1, 2)
        self.spin_pol = QSpinBox()
        self.spin_pol.setRange(config.POLARIZER_STAGE_MIN_ANGLE, config.POLARIZER_STAGE_MAX_ANGLE)
        self.btn_move_pol = QPushButton("Move")
        self.btn_move_pol.clicked.connect(lambda: self.on_manual_move(10))
        self.btn_pol_p45 = QPushButton("+45")
        self.btn_pol_p45.clicked.connect(lambda: self.on_add_angle(self.spin_pol, 45))
        
        layout.addWidget(self.spin_pol, 1, 0)
        layout.addWidget(self.btn_move_pol, 1, 1)
        layout.addWidget(self.btn_pol_p45, 1, 2)
        
        # Sample
        layout.addWidget(QLabel("Sample (Pin 11):"), 2, 0, 1, 2)
        self.spin_samp = QSpinBox()
        self.spin_samp.setRange(config.SAMPLE_STAGE_MIN_ANGLE, config.SAMPLE_STAGE_MAX_ANGLE)
        self.btn_move_samp = QPushButton("Move")
        self.btn_move_samp.clicked.connect(lambda: self.on_manual_move(11))
        self.btn_samp_p45 = QPushButton("+45")
        self.btn_samp_p45.clicked.connect(lambda: self.on_add_angle(self.spin_samp, 45))
        
        layout.addWidget(self.spin_samp, 3, 0)
        layout.addWidget(self.btn_move_samp, 3, 1)
        layout.addWidget(self.btn_samp_p45, 3, 2)
        
        grp.setLayout(layout)
        return grp

    def create_live_view_group(self):
        grp = QGroupBox("Live View")
        layout = QVBoxLayout()
        
        self.lbl_live = QLabel("No Signal")
        self.lbl_live.setMinimumSize(640, 480)
        self.lbl_live.setAlignment(Qt.AlignmentFlag.AlignCenter)
        self.lbl_live.setStyleSheet("background-color: black; color: white;")
        layout.addWidget(self.lbl_live)
        
        self.lbl_live_overlay = QLabel("LIVE PAUSED (Sequence Running)", self.lbl_live)
        self.lbl_live_overlay.setStyleSheet("color: yellow; font-size: 24px; font-weight: bold; background: rgba(0,0,0,150);")
        self.lbl_live_overlay.setAlignment(Qt.AlignmentFlag.AlignCenter)
        self.lbl_live_overlay.setGeometry(0, 200, 640, 80)
        self.lbl_live_overlay.hide()
        
        controls = QHBoxLayout()

        controls.addWidget(QLabel("Filename:"))
        self.edt_snapshot_name = QLineEdit("snapshot")
        self.edt_snapshot_name.setFixedWidth(160)
        controls.addWidget(self.edt_snapshot_name)

        controls.addWidget(QLabel("Save Dir:"))
        self.edt_snapshot_dir = QLineEdit(os.path.join(os.getcwd(), "data"))
        controls.addWidget(self.edt_snapshot_dir)
        self.btn_snapshot_browse = QPushButton("...")
        self.btn_snapshot_browse.setFixedWidth(28)
        self.btn_snapshot_browse.clicked.connect(self.on_snapshot_browse)
        controls.addWidget(self.btn_snapshot_browse)

        controls.addStretch()

        self.btn_snap = QPushButton("Snapshot")
        self.btn_snap.setFixedWidth(110)
        self.btn_snap.clicked.connect(self.on_snapshot)
        controls.addWidget(self.btn_snap)

        layout.addLayout(controls)  # Attach controls to main layout
        
        grp.setLayout(layout)  # CRITICAL: Set layout on group!
        grp.setEnabled(False) # Disabled until camera connects
        self.grp_live = grp
        return grp

    def create_sequence_group(self):
        grp = QGroupBox("Sequence Control")
        layout = QGridLayout()
        
        layout.addWidget(QLabel("Save Directory:"), 0, 0)
        self.edt_save_dir = QLineEdit(os.path.join(os.getcwd(), "data"))
        layout.addWidget(self.edt_save_dir, 0, 1)
        self.btn_browse = QPushButton("...")
        self.btn_browse.clicked.connect(self.on_browse)
        layout.addWidget(self.btn_browse, 0, 2)
        
        layout.addWidget(QLabel("Sample ID:"), 1, 0)
        self.edt_sample_id = QLineEdit("TestSample")
        layout.addWidget(self.edt_sample_id, 1, 1, 1, 2)
        
        layout.addWidget(QLabel("Modes:"), 2, 0)
        modes_box = QHBoxLayout()
        self.chk_crosspol = QCheckBox("Crosspol")
        self.chk_crosspol.setChecked(True)
        self.chk_normal = QCheckBox("Normal")
        self.chk_normal.setChecked(True)
        self.chk_crosspol.toggled.connect(self.on_seq_mode_toggle)
        self.chk_normal.toggled.connect(self.on_seq_mode_toggle)
        modes_box.addWidget(self.chk_crosspol)
        modes_box.addWidget(self.chk_normal)
        modes_widget = QWidget()
        modes_widget.setLayout(modes_box)
        layout.addWidget(modes_widget, 2, 1, 1, 2)
        
        layout.addWidget(QLabel("Crosspol Exposure (us):"), 3, 0)
        self.spin_exp_cross = QSpinBox()
        self.spin_exp_cross.setRange(100, 1000000)
        self.spin_exp_cross.setValue(config.XIMEA_DEFAULT_CROSSPOL_EXPOSURE_US)
        self.spin_exp_cross.setSingleStep(1000)
        layout.addWidget(self.spin_exp_cross, 3, 1, 1, 2)
        
        layout.addWidget(QLabel("Normal Exposure (us):"), 4, 0)
        self.spin_exp_normal = QSpinBox()
        self.spin_exp_normal.setRange(100, 1000000)
        self.spin_exp_normal.setValue(config.XIMEA_DEFAULT_NORMAL_EXPOSURE_US)
        self.spin_exp_normal.setSingleStep(1000)
        layout.addWidget(self.spin_exp_normal, 4, 1, 1, 2)
        
        layout.addWidget(QLabel("Sample Angles (stage deg):"), 5, 0)
        self.edt_angles = QLineEdit("90,60,45,30,0")
        self.edt_angles.setToolTip(
            f"List or range. Examples: 0,30,60 or 0:{config.SAMPLE_STAGE_MAX_ANGLE}:15"
        )
        layout.addWidget(self.edt_angles, 5, 1, 1, 2)
        
        layout.addWidget(QLabel("Settling Time (s, motor settle):"), 6, 0)
        self.spin_settling = QDoubleSpinBox()
        self.spin_settling.setRange(0.1, 10.0)
        self.spin_settling.setValue(config.SETTLING_TIME_S)
        layout.addWidget(self.spin_settling, 6, 1)

        self.btn_start = QPushButton("START SEQUENCE")
        self.btn_start.setStyleSheet("background-color: #4CAF50; color: white; font-weight: bold; padding: 10px;")
        self.btn_start.clicked.connect(self.on_start_sequence)
        layout.addWidget(self.btn_start, 7, 0, 1, 3)
        
        self.progress = QProgressBar()
        layout.addWidget(self.progress, 8, 0, 1, 3)
        
        self.lbl_seq_status = QLabel("Idle")
        layout.addWidget(self.lbl_seq_status, 9, 0, 1, 3)
        
        grp.setLayout(layout)
        return grp

    def create_image_conversion_group(self):
        grp = QGroupBox("Image Conversion")
        layout = QGridLayout()

        layout.addWidget(QLabel("Source Directory:"), 0, 0)
        self.edt_convert_dir = QLineEdit(os.path.join(os.getcwd(), "data"))
        layout.addWidget(self.edt_convert_dir, 0, 1)
        self.btn_convert_browse = QPushButton("...")
        self.btn_convert_browse.clicked.connect(self.on_conversion_browse)
        layout.addWidget(self.btn_convert_browse, 0, 2)

        lbl_hint = QLabel("Converts RAW16 TIFFs in this folder and its direct child folders to RGB8 previews.")
        lbl_hint.setWordWrap(True)
        lbl_hint.setStyleSheet("color: gray; font-size: 10px;")
        layout.addWidget(lbl_hint, 1, 0, 1, 3)

        self.btn_convert_rgb = QPushButton("Convert RAW16 to RGB")
        self.btn_convert_rgb.clicked.connect(self.on_convert_raw16_to_rgb)
        layout.addWidget(self.btn_convert_rgb, 2, 0, 1, 3)

        grp.setLayout(layout)
        self.grp_conversion = grp
        return grp

    # --- LOGIC SLOTS ---

    def on_refresh_ports(self):
        self.cmb_port.clear()
        import serial.tools.list_ports
        ports = [p.device for p in serial.tools.list_ports.comports()]
        def port_key(name):
            m = re.search(r"COM(\d+)", name, re.IGNORECASE)
            return (int(m.group(1)) if m else 10**9, name)
        for dev in sorted(ports, key=port_key):
            self.cmb_port.addItem(dev)
        self.log("COM ports refreshed.")
    
    def on_toggle_connect(self):
        """Arduino Connection Toggle"""
        if self.ctrl.is_connected:
            # Disconnect
            self.ctrl.disconnect()
            self.update_state_ui(STATE_DISCONNECTED)
            self.btn_connect.setText("Connect Controller")
            self.log("Disconnected from Arduino.")
        else:
            # Connect
            port = self.cmb_port.currentText()
            if not port:
                QMessageBox.warning(self, "No Port", "Please select a COM port.")
                return
            try:
                self.ctrl.connect(port)
                # Successful connect logic
                init_state = self.ctrl.get_state() # Should be LATCHED or ARMED (if we reset)
                self.update_state_ui(init_state)
                self.btn_connect.setText("Disconnect Controller")
                self.log(f"Connected to {port}. State: {init_state}")
            except Exception as e:
                QMessageBox.critical(self, "Connection Failed", str(e))
                self.log(f"Connection Error: {e}", "ERROR")

    def _is_camera_connected(self):
        return bool(self.cam_thread is not None or getattr(self.cam, "is_open", False))

    def _set_camera_status(self, status, color):
        self.lbl_cam_status.setText(f" | Camera: {status}")
        self.lbl_cam_status.setStyleSheet(f"font-size: 16px; font-weight: bold; color: {color};")

    def _refresh_camera_ui(self):
        camera_connected = self._is_camera_connected()
        sequence_busy = self.seq_thread is not None and self.seq_thread.isRunning()
        camera_controls_enabled = camera_connected and self.current_state != STATE_RUNNING and not sequence_busy
        if getattr(self, "grp_camera", None):
            self.grp_camera.setEnabled(camera_controls_enabled)
        if getattr(self, "grp_live", None):
            self.grp_live.setEnabled(camera_controls_enabled)
        if getattr(self, "grp_conversion", None):
            self.grp_conversion.setEnabled(not sequence_busy and self.current_state != STATE_RUNNING)
        self.btn_cam_connect.setEnabled(self.current_state != STATE_RUNNING and not sequence_busy)
        self.btn_connect.setEnabled(self.current_state != STATE_RUNNING and not sequence_busy)

    def _start_camera_thread(self):
        if self.cam_thread:
            return
        if hasattr(self.cam, "configure_live_mode"):
            self.cam.configure_live_mode(self.spin_exp.value(), self.spin_gain.value())
        self.cam_thread = CameraThread(self.cam)
        self.cam_thread.new_frame.connect(self.on_new_frame)
        self.cam_thread.error_occurred.connect(self.on_cam_error)
        self.cam_thread.start()

    def _stop_camera_thread(self):
        had_thread = self.cam_thread is not None
        if self.cam_thread:
            self.cam_thread.stop()
            self.cam_thread = None
        return had_thread

    def _disconnect_camera(self, log_message=True):
        self._stop_camera_thread()
        try:
            if hasattr(self.cam, "close"):
                self.cam.close()
        except Exception as e:
            logging.error(f"Camera close failed: {e}")
        self.btn_cam_connect.setText("Connect Camera")
        self._set_camera_status("DISCONNECTED", "gray")
        self.lbl_live.setText("Camera Disconnected")
        self._last_frame_rgb = None
        self._refresh_camera_ui()
        if log_message:
            self.log("Camera Disconnected.")

    def _set_camera_error_ui(self, message="Camera Error"):
        self._stop_camera_thread()
        try:
            if hasattr(self.cam, "close"):
                self.cam.close()
        except Exception as e:
            logging.error(f"Camera close failed during error cleanup: {e}")
        self.btn_cam_connect.setText("Connect Camera")
        self._set_camera_status("ERROR", "red")
        self.lbl_live.setText(message)
        self._last_frame_rgb = None
        self._refresh_camera_ui()
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

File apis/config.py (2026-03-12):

# APIS Configuration Constants

# Serial Settings
SERIAL_BAUDRATE = 9600
SERIAL_TIMEOUT_S = 0.5  # Readline timeout for fast non-blocking feel

# Connection & Logic
MAX_RETRIES = 3
CONNECTION_WAIT_S = 2.0  # Max wait for READY handshake
SETTLING_TIME_S = 1.5    # Default physical settling time (software enforced)
COMMAND_DELAY_S = 0.05   # Min delay between commands to avoid flooding

# Servo Motion Limits
SERVO_MIN_ANGLE = 0
SERVO_MAX_ANGLE = 180

# XIMEA Acquisition Defaults
XIMEA_USE_FIXED_WB = True
XIMEA_WB_KR = 1.40
XIMEA_WB_KG = 1.00
XIMEA_WB_KB = 1.20
XIMEA_DEFAULT_NORMAL_EXPOSURE_US = 18000
XIMEA_DEFAULT_CROSSPOL_EXPOSURE_US = 50000

# Mechanical Transmission
SERVO_GEAR_TEETH = 70
STAGE_GEAR_TEETH = 80

# Convert requested stage angle into servo angle.
# servo_angle = zero_offset + direction * stage_angle * ratio
# Both axes currently use image-derived calibration from data/calibrationsample/normal.
POLARIZER_STAGE_TO_SERVO_RATIO = 1.059
SAMPLE_STAGE_TO_SERVO_RATIO = 1.059
POLARIZER_STAGE_DIRECTION = 1
SAMPLE_STAGE_DIRECTION = 1
POLARIZER_SERVO_ZERO_DEG = 0
SAMPLE_SERVO_ZERO_DEG = 0
POLARIZER_STAGE_MIN_ANGLE = 0
SAMPLE_STAGE_MIN_ANGLE = 0
POLARIZER_STAGE_MAX_ANGLE = int((SERVO_MAX_ANGLE - POLARIZER_SERVO_ZERO_DEG) / POLARIZER_STAGE_TO_SERVO_RATIO)
SAMPLE_STAGE_MAX_ANGLE = int((SERVO_MAX_ANGLE - SAMPLE_SERVO_ZERO_DEG) / SAMPLE_STAGE_TO_SERVO_RATIO)

# Command Codes (Protocol PPAAA)
CMD_POLARIZER = 10
CMD_SAMPLE    = 11
CMD_HOME      = 96
CMD_RESET     = 98
CMD_ESTOP     = 99

# Safety States
STATE_LATCHED = "LATCHED"  # Detached, Boot/Estop
STATE_ARMED   = "ARMED"    # Attached, Normal Operation

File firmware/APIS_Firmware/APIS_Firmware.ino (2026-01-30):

/*
 * APIS: Automated Polarization Imaging System Firmware
 * 
 * Protocol: 9600 baud, "PPAAA\n" line-based.
 * Safety: 
 *   - Boot: LATCHED (Servos detached), prints "READY"
 *   - 99 (ESTOP): Detach all, set LATCHED. Always accepted.
 *   - 98 (RESET): Attach all, set ARMED. Always accepted.
 *   - 10 (Polarizer), 11 (Sample), 96 (HOME): Only accepted if ARMED.
 * 
 * Pins:
 *   - 10: Polarizer Axis (SG90)
 *   - 11: Sample Rotation Axis (HS-318)
 */

#include <Servo.h>

// --- Configuration ---
const int PIN_POLARIZER = 10;
const int PIN_SAMPLE    = 11;
const long BAUDRATE     = 9600;

// --- State Definitions ---
// Safety State Machine:
// LATCHED = true  -> Servos detached, motion blocked. (Boot default, ESTOP state)
// LATCHED = false -> Servos attached, motion allowed. (RESET/ARMED state)
bool isLatched = true; 

Servo servoPolarizer;
Servo servoSample;

// --- Serial Buffer ---
const int MAX_BUF = 32;
char buf[MAX_BUF];
int bufPos = 0;

void setup() {
  Serial.begin(BAUDRATE);
  
  // Power-on safety: Do NOT attach servos yet.
  // Ensure internal state matches "Detached".
  isLatched = true;

  // Boot message
  Serial.println("READY");
}

void loop() {
  while (Serial.available() > 0) {
    char c = Serial.read();

    // Ignore carriage return
    if (c == '\r') continue;

    // Line terminator -> Process Command
    if (c == '\n') {
      buf[bufPos] = '\0'; // Null-terminate
      processCommand(buf);
      bufPos = 0; // Reset buffer
    } 
    else {
      // Buffer overflow protection
      if (bufPos < MAX_BUF - 1) {
        buf[bufPos++] = c;
      } else {
        // Buffer full, discard command but keep reading until \n to clear line
        // We will catch the format error at processCommand or we could flush here.
        // Simple strategy: Set a flag or just let it fail parsing.
        // Let's just consume until \n, then error.
        // For robustness, we'll keep filling the lat slot to force a parse error.
        buf[MAX_BUF - 1] = 'X'; 
      }
    }
  }
}

void processCommand(char* input) {
  // 1. Trim whitespace (simple approach: assuming standard "PPAAA" sans leading spaces, 
  //    but let's be safe against leading/trailing spaces if needed. 
  //    The spec says "exactly 5 digits", so if length != 5, it's FORMAT error.)
  
  // Measure length excluding null terminator
  int len = strlen(input);
  
  // strict "exactly 5 digits" check
  if (len != 5) {
    Serial.println("ERR FORMAT LEN");
    return;
  }

  // Check all are digits
  for (int i = 0; i < 5; i++) {
    if (!isdigit(input[i])) {
      Serial.println("ERR FORMAT DIGIT");
      return;
    }
  }

  // Parse PP and AAA
  char ppStr[3];
  ppStr[0] = input[0];
  ppStr[1] = input[1];
  ppStr[2] = '\0';
  
  char aaaStr[4];
  aaaStr[0] = input[2];
  aaaStr[1] = input[3];
  aaaStr[2] = input[4];
  aaaStr[3] = '\0';

  int pp = atoi(ppStr);
  int aaa = atoi(aaaStr);

  // --- Command Handler ---

  // Priority 1: ESTOP (PP=99) - Always accepted
  if (pp == 99) {
    performEstop();
    Serial.println("OK ESTOP");
    return;
  }

  // Priority 2: RESET (PP=98) - Always accepted
  if (pp == 98) {
    performReset();
    Serial.println("OK RESET");
    return;
  }

  // All other commands require ARMED state (isLatched == false)
  if (isLatched) {
    Serial.println("ERR ESTOP_LATCHED");
    return;
  }

  // Priority 3: HOME (PP=96)
  if (pp == 96) {
    servoPolarizer.write(0);
    servoSample.write(0);
    // IMMEDIATE ACK
    Serial.println("OK HOME");
    return;
  }

  // Axis Move Commands
  if (pp == 10) { // Polarizer
    if (aaa < 0 || aaa > 180) {
      Serial.println("ERR RANGE");
      return;
    }
    servoPolarizer.write(aaa);
    // IMMEDIATE ACK
    Serial.print("OK 10 ");
    printAngle3(aaa);
    Serial.println();
    return;
  }

  if (pp == 11) { // Sample
    if (aaa < 0 || aaa > 180) {
      Serial.println("ERR RANGE");
      return;
    }
    servoSample.write(aaa);
    // IMMEDIATE ACK
    Serial.print("OK 11 ");
    printAngle3(aaa);
    Serial.println();
    return;
  }

  // Unknown PP
  Serial.print("ERR PIN ");
  Serial.println(pp);
}

void performEstop() {
  // Detach immediately to release torque
  servoPolarizer.detach();
  servoSample.detach();
  isLatched = true;
}

void performReset() {
  // Re-attach servos
  if (!servoPolarizer.attached()) servoPolarizer.attach(PIN_POLARIZER);
  if (!servoSample.attached())    servoSample.attach(PIN_SAMPLE);
  
  isLatched = false;
}

// Helper to print angle as 3 digits (e.g. 090)
void printAngle3(int val) {
  if (val < 10) Serial.print("00");
  else if (val < 100) Serial.print("0");
  Serial.print(val);
}

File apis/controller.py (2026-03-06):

import serial
import time
import threading
import logging
from . import config, utils

class PicsController:
    def __init__(self):
        self.ser = None
        self.lock = threading.Lock()
        self.is_connected = False
        self.last_state = config.STATE_LATCHED 
        self.port = None

    def connect(self, port, baud=config.SERIAL_BAUDRATE):
        """
        Connect to Arduino.
        Handshake policy:
        1. Open port (flush I/O).
        2. Wait for 'READY\\n' (Arduino boot message).
        3. If no 'READY' within timeout, assume it's already on and send RESET.
        4. If RESET fails, raise Error.
        """
        self.port = port
        logging.info(f"Connecting to {port} at {baud}...")

        try:
            self.ser = serial.Serial(port, baud, timeout=config.SERIAL_TIMEOUT_S)
            time.sleep(2.0) # wait for DTR reset pulse usually implies boot, but allow time. 
            # Note: On some Arduino/OS combos, opening serial resets the board (bootloader runs).
            # We wait for 'READY'.
            
            self.ser.reset_input_buffer()
            self.ser.reset_output_buffer()

            # Attempt 1: Listen for Boot Message
            # Only wait up to CONNECTION_WAIT_S for initial line
            start_t = time.time()
            boot_msg_seen = False
            
            while (time.time() - start_t) < config.CONNECTION_WAIT_S:
                if self.ser.in_waiting:
                    line = self.ser.readline().decode('utf-8', errors='ignore').strip()
                    if line == "READY":
                        boot_msg_seen = True
                        break
                time.sleep(0.1)

            if boot_msg_seen:
                logging.info("Arduino BOOT detected (READY). State is LATCHED.")
                self.is_connected = True
                self.last_state = config.STATE_LATCHED
                # Optional: Send RESET to arm it?
                # Spec says: Boot -> LATCHED. User must explicit Reset to Arm.
                # So we leave it as LATCHED.
                return True

            # Attempt 2: Fallback (Arduino was already on) -> Force RESET
            logging.warning("No READY received. Sending FORCE RESET...")
            resp = self._send_raw_command(config.CMD_RESET, 0)
            if "OK RESET" in resp:
                logging.info("Force RESET successful. Connected & ARMED.")
                self.is_connected = True
                self.last_state = config.STATE_ARMED
                return True
            else:
                raise ConnectionError(f"Failed to connect. Response to RESET: {resp}")

        except Exception as e:
            self.is_connected = False
            if self.ser and self.ser.is_open:
                self.ser.close()
            logging.error(f"Connection failed: {e}")
            raise e

    def disconnect(self):
        with self.lock:
            if self.ser and self.ser.is_open:
                self.ser.close()
            self.is_connected = False

    def _send_raw_command(self, pp, aaa, retry_count=config.MAX_RETRIES):
        """
        Internal: Send PPAAA, return raw response line.
        Protected by Lock.
        Handles Retries on TIMEOUT.
        """
        cmd_str = utils.format_command(pp, aaa)
        
        # Lock entire I/O transaction
        with self.lock:
            if not self.ser or not self.ser.is_open:
                return "ERR NO_CONNECTION"
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
